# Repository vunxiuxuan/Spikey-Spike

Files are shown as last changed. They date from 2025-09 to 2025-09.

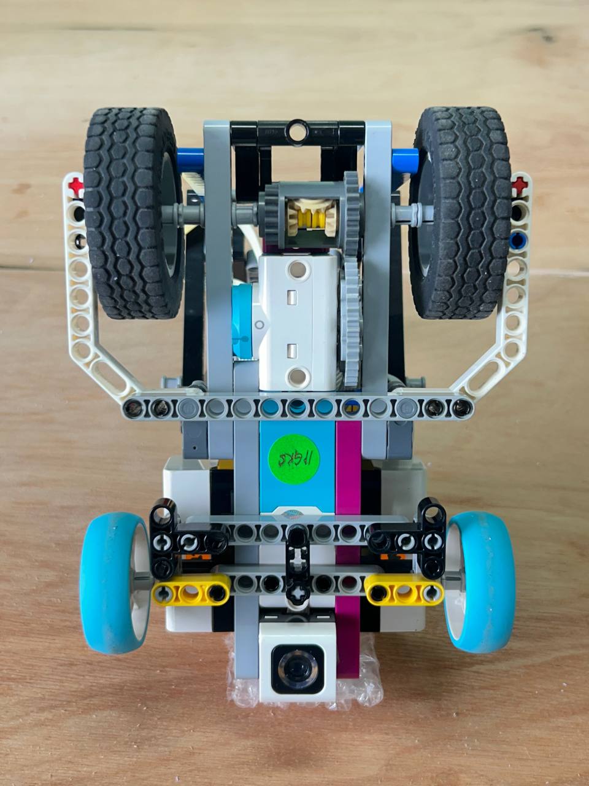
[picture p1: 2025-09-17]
v-photos/bottom.jpg

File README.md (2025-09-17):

# Content (GitHub)
**schemes** This folder contains one or several schematic diagrams in the form of JPEG, PNG, or PDF of the electromechanical components illustrating all the elements (electronic components and motors) used in the vehicle and how they connect. This folder also included the schematic diagram of the robot for both open and obstacle challenge.

**src** This folder contains all the programming flowcharts and all programming used to participate in the WRO 2025 Future Engineers Category.

**t-photos** This folder contains photos of the team participating in the WRO 2025 Future Engineers Category.

**v-photos** This folder contains photos of the vehicle from all sides (top view, bottom view, front view, back view and side views)

**video** This folder contains video.md file that demonstrates how the robot functions to solve both challenges.

**models** This folder contains the robot building insturction and the 3D printed part building instruction that installed on the vehicle. The file is presented in .lxf, .ldr and .ldr format.

**other** This folder contains other files which can be used to understand how to prepare the vehicle for the competition.

# Table of Contents
- [Introduction](#introduction)
- [X-UniTech Team, Malaysia](#x-unitech-team-malaysia)
- [Performance video](#performance-video)

- [1.0 Mobility management](#10-mobility-management)
  - [1.1 Design of the self-driving car](#11-design-of-the-self-driving-car)
  - [1.2 Self-driving car steering](#12-self-driving-car-steering)
  - [1.3 Self-Driving Car Chassis](#13-self-driving-car-chassis)
  - [1.4 Building of the self-driving car](#14-building-of-the-self-driving-car)

- [2.0 Power and sense management](#20-power-and-sense-management)
  - [2.1 Power supply](#21-power-supply)
  - [2.2 Sensing elements](#22-sensing-elements)
  - [2.3 Build Of Materials (BOM)](#23-build-of-materials-bom)
  - [2.4 Electrical Diagram](#24-electrical-diagram)

- [3.0 Obstacle Management](#30-obstacle-management)
  - [3.1 Open Challenge](#31-open-challenge)
  - [3.2 Obstacle Challenge](#32-obstacle-challenge)

- [4.0 Engineering Factors](#40-engineering-factors)
- [5.0 Improvement and Enhancement](#50-improvement-and-enhancement)
- [Credits](#credits)

- [Appendix 1. Building Guide](#appendix-1-building-guide)
- [Appendix 2. Open Challenge Coding](#appendix-2-open-challenge-coding)
- [Appendix 3. Obstacle Challenge Coding](#appendix-3-obstacle-challenge-coding)

---

# Introduction
This engineering documentation covers the car’s mobility management, power and sensor systems, obstacle detection and avoidance, construction design, integration of third-party sensors, and the improvements made throughout our preparation for the World Robot Olympiad Open Championship Philippines (WRO) 2025 Future Engineers Category Competition.

# X-UniTech Team, Malaysia
X-UniTech from Malaysia is a team of three members who work together to build and program a self-driving robot car. We design, build, and manage all the electronic and mechanical parts to ensure our self-driving car runs smoothly. Here are our team members:

Vun Xiu Xuan, Alvin Kong Wei Ee, and Jennissa Aing Anak Jim.




# Performance video
This video provides an overview of our self-driving car’s design, demonstrates its performance in both the Open Challenge and the Obstacle Challenge, and explains how it operates in each scenario. Scan the QR code below to watch the video for both challenges.



# 1.0 Mobility management
This section explains how our self-driving car is designed, how the motors are used to control its movement, and how they are connected to the vehicle. It also describes the chassis and where different parts are placed. Lastly, it introduces basic engineering ideas like speed, torque, and power that affect how the car works.

## 1.1 Design of the self-driving car
The autonomous self-driving car is constructed using the LEGO® Education SPIKE™ Prime Set (45678). The building instruction of the robot can be obtained through Appendix 1.



The figure below displays the images of the self-driving car that we have designed and constructed.

Top view



Bottom view



Front view



Back view



Left side view



Right side view



## 1.2 Self-driving car steering
Our design applies Ackermann steering geometry, where the front wheels turn at slightly different angles. This allows the inner and outer wheels to follow separate paths during a turn, minimizing slip and friction. As a result, the vehicle remains stable, the tires are more durable, and it can handle sharp turns without skidding or losing balance.



## 1.3 Self-Driving Car Chassis
The chassis design of the self-driving car plays a crucial role in providing structural integrity and maintaining stability during fast maneuvers, including sharp turns and sudden accelerations. The robot implements the differential gear to help its run smoothly. The differential gear transfers power between the two axles, enabling them to rotate at different speeds. This mechanism allows the self-driving car to execute smooth turns, especially when navigating around inner wall corners during Open Challenge.



## 1.4 Building of the self-driving car
The building instruction for the self-driving car and the video of showcasing the 3D printing process of its parts can be accessed via the QR Code below. 

Building Instruction of Self-Driving Car (PDF format)



# 2.0 Power and sense management
This section highlights the critical pieces that sustain the reliable operation and intelligent functionality of the LEGO® SPIKE Prime Self-Driving Car.

## 2.1 Power supply
The power supply is provided by the LEGO® SPIKE Prime rechargeable hub, delivering stable energy to motors, sensors, and the control unit while minimizing fluctuations that could disrupt performance. 



## 2.2 Sensing elements
This section introduces the sensors that are used on the Self-Driving Car. Sensors form the core perception system of the LEGO® SPIKE Prime vehicle, enabling it to detect, interpret, and respond to its environment.



i) Distance Sensor of LEGO® Education SPIKE™

The Spike Distance Sensor is used on our robot to detect the distance between the robot and the wall. In the Open Challenge, we used the distance sensor to keep the robot aligned with the wall and to perform turns when the wall was no longer detected nearby. In the Obstacle Challenge, the distance sensor was used to detect the wall and the boundaries of the parking lot before doing the parking.



ii) Color Sensor of LEGO® Education SPIKE™

The Spike Color Sensor is used to detect the blue or orange lines on the map. In the Obstacle Challenge, we used the color sensor to detect these lines at corners, allowing the robot to determine for turning.



iii) Build-in Gyro Sensor in LEGO® SPIKE Prime hub

The built-in gyro is used to keep the robot moving in a straight line and to perform turns accurately. The Spike built-in gyro calculates the robot’s angle precisely, ensuring that its movement remains straight. 



iv) ESP-32 Cam

The ESP-32 Cam was used by our team to detect obstacles on the map during the Obstacle Challenge. The camera helps the robot identify the color of the pillars and decide whether to avoid them by turning left or right.



## 2.3 Build Of Materials (BOM)
List below shows the parts of LEGO® Education SPIKE™ Prime Set (45678) that is used for the assembly of the Self-Driving Car.















## 2.4 Electrical Diagram
The wiring diagram presents the interconnections linking the power supply, central hub, sensors, and actuators. It gives a guide for the system assembly, fault detection and ongoing maintenance.

(i) Open challenge wiring diagram 



(ii) Obstacle challenge wiring diagram



# 3.0 Obstacle Management
In our project, we utilize the LEGO Education Spike programming language to operate the robot. The programming structure is divided into two main sections which is the Open Challenge and the Obstacle Challenge. This section includes a flowchart and an overview of the code used for both challenges. 

## 3.1 Open Challenge
The right distance sensor is used to determine whether the vehicle goes clockwise or counterclockwise during the Open Challenge round while left and right distance sensors are used to maintain the distance of the self-driving car between the inner and outer walls. The vehicle needs to complete 12 rounds to finish the challenge. Below shows the flow chart for the Open Challenge.



Appendix 2 contains the complete programming code for the Obstacle Challenge. 
We will have a look at the details for the coding of Open Challenge.



This part of the program is used to calculate the values from the gyro sensor in order to keep the robot moving in a straight line. By continuously reading the orientation data from the gyro, the robot can detect even small deviations from its intended path. These values are then processed and used to make corrective adjustments to the motors, ensuring the vehicle maintains a stable and accurate trajectory. This function is very important, as it prevents the robot from drifting sideways and helps it stay aligned while performing autonomous tasks.



This part of the program is responsible for reading the values from both the gyro sensor and the ultrasonic sensor. The gyro provides orientation data that helps the robot maintain its direction and stability, while the ultrasonic sensor measures distances to nearby objects. By combining these two inputs, the robot can not only move in a straight line but also avoid obstacles effectively. This integration of sensor data is important for improving navigation accuracy and ensuring the robot can adapt to changes in the environment while completing its tasks.



This part of the program is used to reset the steering system at the beginning of the run. It ensures that the front wheels of the robot are aligned at the centre position when the program starts. By doing this, the robot begins in a neutral steering state, which provides a stable baseline for all subsequent movements. This step is important because any misalignment at the start could cause the robot to drift or turn unintentionally, affecting the accuracy of navigation and task performance.



This part of the program is responsible for calculating the steering angle of the robot. By determining the exact angle, the system can adjust the front wheels more precisely, allowing the robot to turn with greater accuracy and stability. This calculation helps reduce unnecessary friction and prevents sudden or jerky movements during a turn. As a result, the steering becomes smoother, and the robot can navigate corners or curves more efficiently while maintaining balance and control.



This part of the program combines the values received from multiple sensors, including the gyro, ultrasonic sensor, and colour or vision sensors. By processing these inputs together, the robot can make smarter decisions while navigating. The combined data is used to control the steering system when making turns and to ensure that the robot avoids walls or other obstacles in its path. This sensor fusion approach allows the robot to react more accurately to its environment, providing smoother turns, better obstacle avoidance, and more reliable performance during the challenge.



This block is used to control the movement of the robot by rotating the rear wheels according to a specified number of degrees. By setting the wheel rotation in degrees, the program can precisely determine how far the robot should travel. This method provides better accuracy compared to timed movements, as it is directly based on the wheel’s rotation. It helps ensure consistent and predictable motion, which is important for completing tasks and following the planned path.



This block is used to control the movement of the robot based on the number of degrees that we input. By specifying the rotation in degrees, the program can accurately determine the distance the robot should travel. This approach makes the movement more consistent and reliable, as it directly relates to the wheel’s rotation rather than relying on time-based control. It allows the robot to perform tasks with better precision and follow the planned route more effectively.



This block is used to set the origin values for all the variables in the program. By initializing these variables at the start, the robot begins its operation with a clean and consistent baseline. This step is important because it prevents errors that might occur if the variables still hold old or undefined values from previous runs. Proper initialization ensures that all sensors, counters, and control parameters start from the correct reference point, allowing the robot to function accurately and reliably throughout the task.



This block represents the start of the main program, where the robot determines whether it should move in a clockwise or counterclockwise direction. At this stage, the robot reads input from its sensors, such as the camera or color detector, to analyse its surroundings and decide the correct orientation. This decision is crucial because it sets the initial path for the robot, influencing how it will navigate the rest of the challenge. By establishing the direction at the very beginning, the program ensures that the robot follows a consistent and reliable strategy throughout its tasks.



This block represents the main loop of the program, where the robot is programmed to move a certain number of degrees that have been predetermined. The robot continues this movement until it detects a line on the map using its color sensor. Each time this process is completed, it is counted as one loop. The robot is designed to repeat this cycle a total of 11 times to fulfill the challenge requirements. After completing the loops, the robot then moves an additional 1000 degrees to return to the starting area, ensuring the task is finished accurately and consistently.

## 3.2 Obstacle Challenge
The ESP-32 cam is added in to assist the robot identifying the pillars during the round. Below shows the flow chart for the coding of Obstacle Challenge.



Appendix 3 contains the complete programming code for the Obstacle Challenge. 

We will have a look at the details for the coding of Open Challenge.





Above coding is used for the set up of the build-in gyro, colour sensor, ultrasonic sensor and camera on the robot. This part is used to save the sensor data into a variable.



 This simplified block is used for the steering. This block help steering had a more sensitive and accurate angle to turn. 

 



This block is known as ‘Drive’. This block is used to calculate all the sensor data and combine all of them to control the steering turning.





This block is known as ‘Drive Degrees’ which is used to move the robot by calculating the degrees of the rear wheel turning until the degrees that we need and the robot will stop.





This block is known as ‘Steering Drive’ which used for turning the robot with the calculation of the rear wheel degrees.



This simplified block is known as ‘Drive 3 Round’. This block is the programme that is used for turning the map for three rounds. The robot will move 1000 degrees and move until it detects a colour line on the map and will add on 90 degrees to turn. This will be known as a loop and the robot will repeat the loop for 12 times.

Below is the main program to set an original value for all the variables.



This section of the robot’s function is specifically designed to handle the process of exiting the parking zone and making directional decisions. When the robot comes out of the parking area, it needs to determine whether it should move clockwise or counterclockwise around the arena. This decision is based on the input received from its sensors, which analyse the surrounding environment and detect possible obstacles or reference markers. By doing so, the robot ensures that it follows the correct path while avoiding collisions and maintaining smooth navigation. This step is crucial because it sets the initial direction of movement, which will affect how the robot approaches the rest of the tasks in the challenge.



This part of the program is responsible for enabling the robot to detect a colored line on the map, which acts as a signal for the robot to make a turn. At the same time, the system also keeps track of how many loops the robot has completed. By combining line detection with loop counting, the robot can follow the course more accurately and avoid getting lost. This feature is especially important because it allows the robot to understand its position on the track and make sure it performs the required number of turns and laps according to the challenge.



 This part of the program is designed for the robot to search for the magenta-colored wall, which acts as a key marker in the challenge. Once the wall is detected, the robot uses this information to decide its parking strategy, specifically whether it should park in a clockwise or counterclockwise direction. By recognizing the magenta wall as a reference point, the robot can make a clear decision on how to approach the parking zone, ensuring accuracy and consistency in its movement. This process is important because it allows the robot to adapt its path based on visual cues, rather than following only pre-set movements.

# 4.0 Engineering Factors
This section highlights our custom-built and third-party open-source components, accompanied by detailed descriptions of each part integrated into the car.
Our robot used a third-party component which is a 3D printed camera holder. A 3D-printed camera holder is used to securely mount the sensor, ensuring it remains stable even during motion or sharp turns. This stability allows the ESP32-Cam to consistently capture crucial data for recognizing and interpreting traffic signs, thereby enhancing the robot’s responsiveness to its surroundings and improving performance in both the Open Challenge and Obstacle Challenge.



# 5.0 Improvement and Enhancement
This section describes the challenges encountered during the development of our self-driving car and the approaches we applied to overcome them. Through careful analysis of each issue, we introduced modifications that enhanced the car’s overall performance.
One of the issues we faced during the challenge is the wheels tended to hit walls during traffic sign avoidance, so we added crash barriers on both sides of the robot. 



These barriers act as buffers, redirecting the robot away from obstacles before the tires make contact. This reduces friction and prevents the robot from getting stuck, allowing it to move smoothly without obstruction.
Another issue we worked on was in the programming. In the Open Challenge, we initially used the color sensor to scan the line (orange for clockwise and blue for anticlockwise) so the robot could decide when to turn left or right. However, the color sensor sometimes failed to detect the line, which caused the robot to miss turns. 



To overcome this, we replaced the color sensor with the ultrasonic sensor. With this improvement, the ultrasonic sensor measures the distance from the wall, and if the value is greater than 2000, the robot recognizes that it has reached the edge of the wall and makes the turn. This adjustment increased the robot’s accuracy and reliability, ensuring smoother navigation throughout the challenge.



# Credits
We acknowledge the use of LEGO® Education SPIKE™ Prime in this project.  LEGO®, the LEGO logo, and SPIKE™ are trademarks of the LEGO Group.  This project is an independent creation and is not sponsored, authorized, or endorsed by the LEGO Group.

# Appendix 1. Building Guide




























































































































































































# Appendix 2. Open Challenge Coding




















# Appendix 3. Obstacle Challenge Coding


























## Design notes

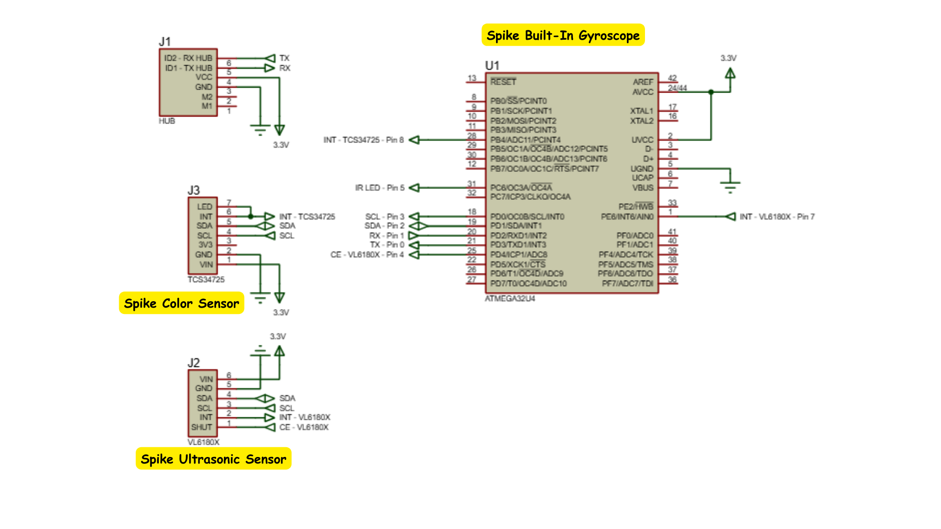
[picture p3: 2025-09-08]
schemes/Spike Schematic Diagram.png

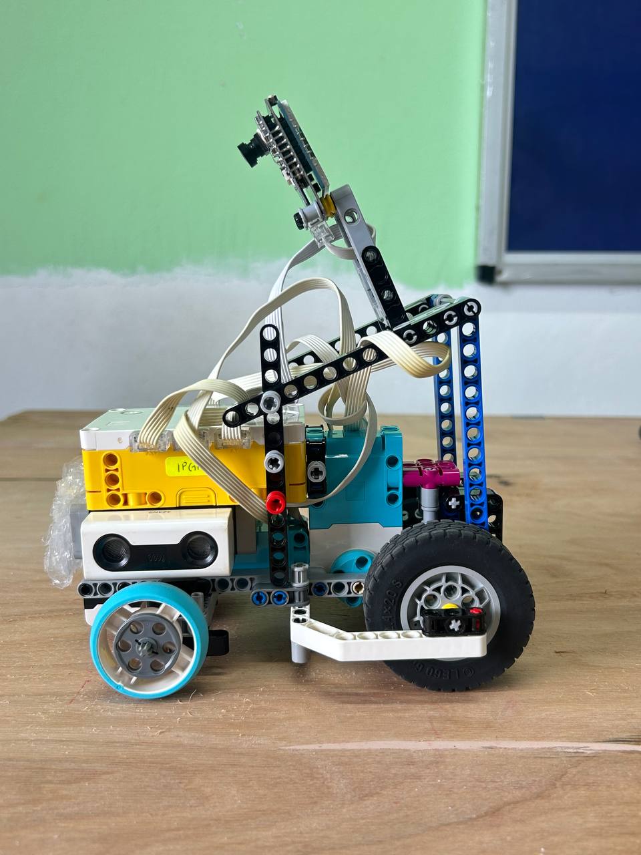
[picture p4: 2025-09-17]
v-photos/left.jpg

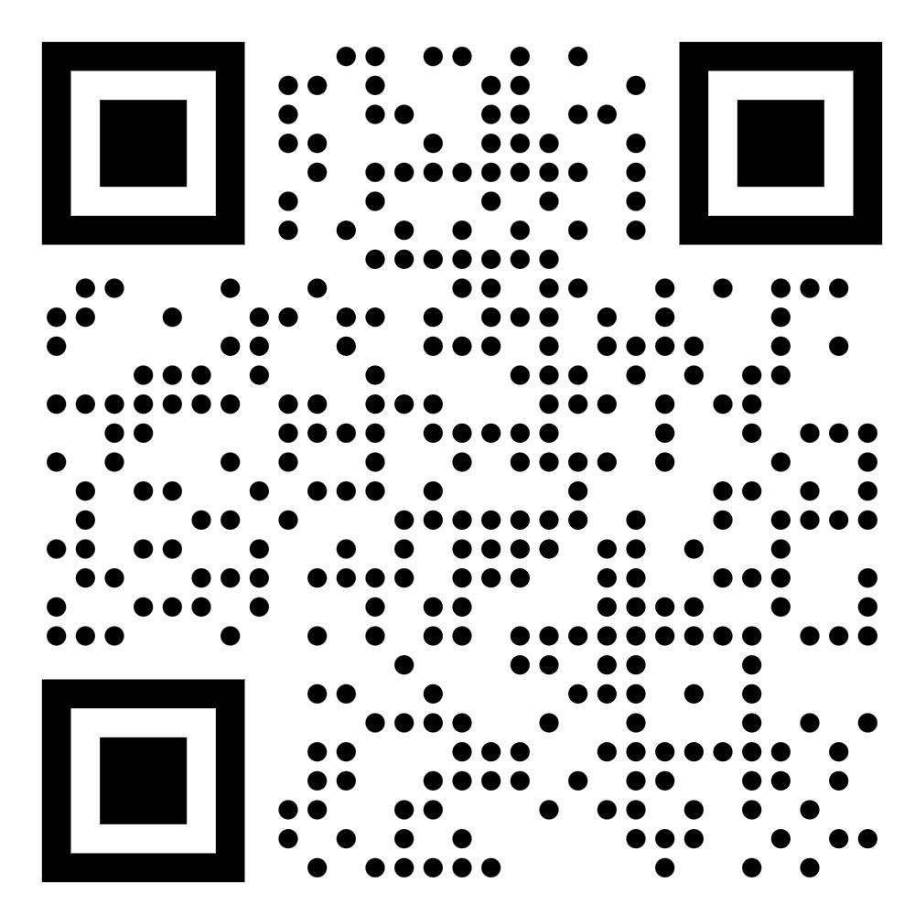
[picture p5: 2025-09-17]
video/Spike Demo Video.jpg

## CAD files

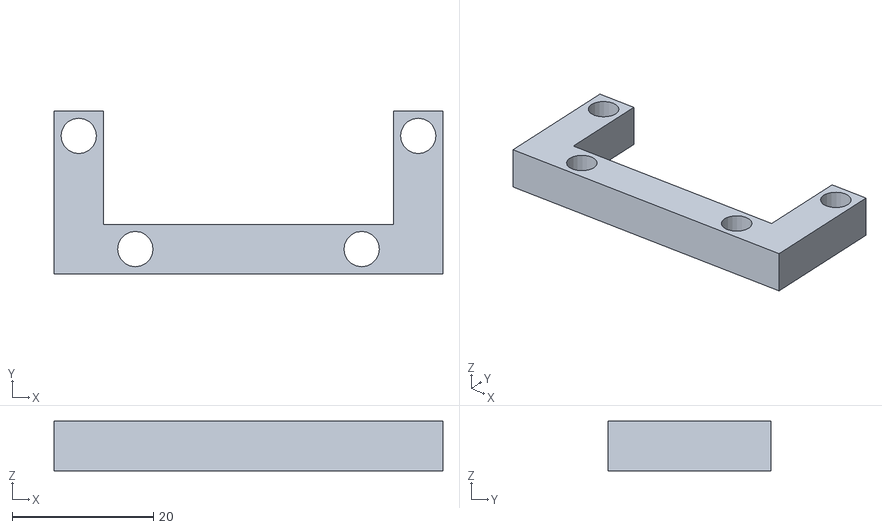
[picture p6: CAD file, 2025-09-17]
models/Spike Camera Holder.stl
55.0 x 23.0 x 7.00

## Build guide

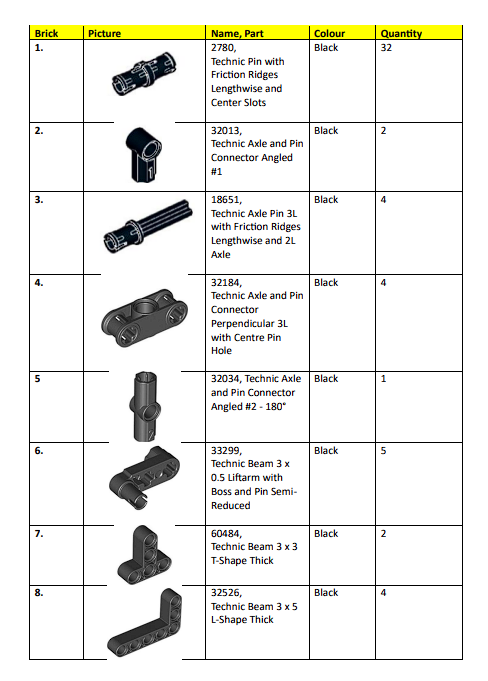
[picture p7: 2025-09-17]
models/Spike Build of Material/1.png
